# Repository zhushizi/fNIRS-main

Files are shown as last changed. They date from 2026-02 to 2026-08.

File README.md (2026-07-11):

# fNIRS 双接收源五波长上位机软件

本仓库现在只保留 **上位机软件部分**，并已切换到 **双接收源 + 五波长** 的 26B 串口协议。
软件接收 `S1_D1`（长距 3.0 cm）与 `S1_D2`（短距 1.0 cm）两个接收源、五个光源波长（850 / 810 / 770 / 730 / 700 nm）的光强数据，完成采集、配对、短距回归校正（SSR）、广义 MBLL 与 rSO₂ 估算，输出 **HbO / HbR / Cyt** 三色团浓度变化以及 **rSO₂**。

> 数据链路：安卓 App 独占 UART 启停，把设备串口字节经 **TCP/JSON** 转发给 PC 解码端（PC 作为 TCP Server 被动接收）。PC 端在采集中并行做在线分析并把结果回传安卓绘图，采集结束后再做一次离线终算落盘。

## 当前协议摘要

- **波特率**：`115200`
- **帧头**：`0x55 0xAA`
- **固定帧长**：`0x1A`（26 字节）
- **帧类型**：
  - `0x01`：指令帧（上位机 -> 下位机）
  - `0x02`：数据帧（下位机 -> 上位机）
  - `0x03`：应答帧（双向 ACK）
- **payload**：`21B`
- **校验**：从长度字节到 payload 末尾的累加和低字节
- **当前固件不回 ACK**：`protocol.send_frame_with_ack` 暂时跳过 ACK 判断（由安卓侧控制 UART）

## 当前几何与算法假设

- **物理通道**：双接收源
  - `S1_D1`：源探距离默认 `3.0 cm`（长距，配置在 `software/config.py`）
  - `S1_D2`：源探距离默认 `1.0 cm`（短距，用于短距回归校正）
- **波长编码**（数据帧 payload byte0 = `Wavelength`）：
  - `0x00`：未点亮（OFF，配对前丢弃）
  - `0x01`：850nm
  - `0x02`：810nm
  - `0x03`：770nm
  - `0x04`：730nm
  - `0x05`：700nm
- **接收源编码**（数据帧 payload byte1 = `DetectorId`）：
  - `0x01`：`S1_D1`
  - `0x02`：`S1_D2`
- **采样值**：payload `byte2:6`，4 字节大端无符号
- **采集通道编码**（数据帧 payload byte6 = `ChannelId`，与接收源/波长正交）：
  - `0x01`：通道1
  - `0x02`：通道2
  - `0x00`/缺省：归入通道1
  - 每个采集通道内部各有完整的双接收源×五波长，反演链路在每个通道内各跑一套；回传安卓时用 `channel` 字段区分
- **反演**：分步广义 MBLL 先解 HbO/HbR，再从残差投影估 Cyt（oxCCO，UCL-NIR 差分消光系数）
- **rSO₂**：基于 30–60s 基线段假设（基线 HbT≈80μM、rSO₂≈65%）把 ΔHbO/ΔHbR 转成血氧饱和度
- **输出通道**：由 `config.OUTPUT_CHANNEL` 选择，可选 `S1_D1` / `S1_D2` / `S1_D1_ssr`，默认 `S1_D1_ssr`（短距回归校正后的长距通道）

## 快速开始

1. 安装依赖

```bash
cd software
pip install -r requirements.txt
```

2. 配置参数

编辑 `software/config.py`：

- `SERIAL_PORT`（仅旧串口脚本使用）
- `BAUD_RATE`
- `HOST_TCP_DEFAULT_PORT`（安卓 TCP 连接端口，默认 `9000`）
- `DETECTOR_CHANNELS` / `WAVELENGTH_CHANNELS`（几何与波长表）
- `OUTPUT_CHANNEL`（输出通道）

3. 运行方式（当前主链路）

```bash
cd software
# 启动 TCP 解码端，等待安卓连接；采集 + 在线回传 + 离线终算
python fNIRS_processing.py

# 同时在 PC 端镜像绘制发往安卓的曲线
python fNIRS_processing.py --live_plot

# 打印 TCP 收发日志
python fNIRS_processing.py --tcp_debug
```

## 输出文件

每次采集在 `software/result_table/<时间戳>/` 下生成一组文件。**采集通道相关的文件按通道各写一份**（后缀 `_ch1` / `_ch2`），原始数据合写一份并带 `ChannelId` 列：

- `all_groups.csv`
  - 原始采集数据（所有通道合写一份）
  - 列：`Time (s), ChannelId, DetectorId, Channel, Wavelength, Value`
- `interleaved_output_ch{n}.csv`
  - 该通道 2 接收源 × 5 波长配对后的光强宽表
  - 列：`Time (s), S1_D1_850, S1_D1_810, ..., S1_D2_700`
- `processed_output_ch{n}.csv`
  - 该通道广义 MBLL + SSR 输出（列前缀取自 `OUTPUT_CHANNEL`）
  - 列风格：`Time, S1_D1_ssr_hbo, S1_D1_ssr_hbr, S1_D1_ssr_cyt`
- `android_live_output_ch{n}.csv`
  - 该通道在线分析过程中实际回传安卓的曲线副本

> 只出现一个通道时就只生成该通道那一套文件（例如仅通道1 时只有 `*_ch1.csv`）。

## 主要文件

- `software/config.py`：串口/TCP 参数、几何与五波长表、消光系数、输出通道
- `software/protocol.py`：26B 协议组帧 / 拆帧 / 校验
- `software/fNIRS_processing.py`：主入口（解析参数后调用 `run_pipeline`）
- `software/fnirs_pipeline/`：采集 → 预处理 → 配对 → MBLL/SSR 的离线/在线管线
- `software/online_android/`：安卓 TCP 桥接、在线分析后台线程、rSO₂、回传与绘图

更详细的数据链路说明见 `software/fNIRS_processing_pipeline.md` 与 `software/README.md`。

## 历史 / 单通道脚本

下列脚本来自旧的单通道双波长（660/940）版本，部分仍走本地串口，主链路已不再使用，仅作参考或离线回放：
`adc_live.py`、`adc_animation.py`、`mBLL_animation.py`、`visualizer.py`（+ `index.html`）、`hbo_hbr_live.py`、`data_analysis.py`、`nirs_viewer.py`、`rso2_from_processed.py`。

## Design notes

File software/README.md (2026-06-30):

# fNIRS Dual-Detector Five-Wavelength Software

This directory contains the host-side software for the **dual-detector, five-wavelength** fNIRS workflow.
It targets the **26-byte framed serial protocol** carried over an **Android TCP bridge**, and assumes two
receiver channels — `S1_D1` (long, 3.0 cm) and `S1_D2` (short, 1.0 cm) — each sampled under five emitter
wavelengths (`850 / 810 / 770 / 730 / 700 nm`).

The Android app owns the UART (start/stop), forwards raw serial bytes to the PC over TCP/JSON, and the PC
acts as a passive TCP **server** that decodes frames, runs analysis, and streams `HbO / HbR / Cyt / rSO₂`
results back to the phone for live plotting.

## Core Features

- **Framed serial protocol** (`protocol.py`)
  - `0x55 0xAA` frame header
  - fixed `26B` frame length
  - checksum validation
  - current firmware does not ACK; `send_frame_with_ack` skips the ACK wait

- **Android TCP bridge** (`online_android/tcp_bridge.py`)
  - PC listens on `HOST_TCP_DEFAULT_PORT` (default `9000`)
  - Android sends `serial_data` (base64-encoded raw frames); PC exposes a serial-like `read()`
  - PC sends back `live_analysis_batch` and `analysis_result`

- **Dual-detector acquisition**
  - one intensity value per data frame, tagged with detector id and wavelength code
  - raw capture stored in `all_groups.csv`

- **Processing**
  - per-(detector, wavelength) low-pass filtering
  - segment RMS by `(DetectorId, Wavelength)` runs
  - 2 detectors × 5 wavelengths pairing into an intensity wide table
  - intensities → OD changes → robust band-pass (with decimation)
  - **short-separation regression (SSR)**: short detector regressed out of the long detector
  - **stepwise generalized MBLL**: solve HbO/HbR first, then estimate Cyt from the residual projection
  - **rSO₂** estimation from ΔHbO/ΔHbR over a fixed baseline window

- **Online + offline**
  - online: background worker re-runs the full session each tick and streams full series to Android
  - offline: after capture finishes, a final pass writes `processed_output.csv`

## Protocol Summary

### Common Frame Layout

| Field | Size |
|---|---|
| Header | 2 bytes (`0x55 0xAA`) |
| Length | 1 byte (`0x1A`) |
| Type | 1 byte |
| Payload | 21 bytes |
| Checksum | 1 byte |

### Frame Types

- `0x01`: command frame
- `0x02`: data frame
- `0x03`: ACK frame

### Command Payload (`0x01`)

| Byte | Meaning |
|---|---|
| 0 | start/stop (`0x00` stop, `0x01` start) |
| 1 | intensity (`0x00`~`0xFF`) |
| 2 | channel/command code |
| 3-20 | reserved, currently `0x00` |

### Data Payload (`0x02`)

| Byte | Meaning |
|---|---|
| 0 | wavelength code (`0x00=off`, `0x01=850`, `0x02=810`, `0x03=770`, `0x04=730`, `0x05=700` nm) |
| 1 | detector id (`0x01=S1_D1`, `0x02=S1_D2`) |
| 2-5 | sampled value, 4-byte big-endian unsigned |
| 6-20 | reserved |

`Wavelength=0x00` (off) rows are dropped before wavelength pairing.

## Configuration

Edit `config.py` before running:

- `SERIAL_PORT`, `BAUD_RATE` (legacy single-channel serial scripts only)
- `HOST_TCP_LISTEN_HOST`, `HOST_TCP_DEFAULT_PORT` (Android TCP bridge)
- `DETECTOR_CHANNELS` (names, codes, source-detector distances)
- `WAVELENGTH_CHANNELS` (codes + emitter/MBLL wavelengths)
- `OUTPUT_CHANNEL` (`S1_D1` | `S1_D2` | `S1_D1_ssr`, default `S1_D1_ssr`)
- `BP_LOW_HZ` / `BP_HIGH_HZ` / `BP_ORDER` (OD band-pass)

`config.py` validates these tables on import (`_validate_wavelength_channels`, `_validate_output_channel`).

## Main Entry Point

### `fNIRS_processing.py`

Thin CLI wrapper. Parses TCP options and calls `fnirs_pipeline.run_pipeline`, which:

1. opens the Android TCP bridge and waits for a client,
2. captures raw frames into `all_groups.csv` while a background worker streams live analysis,
3. builds `interleaved_output.csv` (paired intensities),
4. runs SSR + generalized MBLL and writes `processed_output.csv`,
5. sends a final `analysis_result` to Android.

```bash
python fNIRS_processing.py                 # capture + online + offline
python fNIRS_processing.py --live_plot     # also mirror the Android stream on a PC plot
python fNIRS_processing.py --tcp_debug     # print TCP rx/tx logs
```

## CSV Outputs

Written under `result_table/<timestamp>/`.

### `all_groups.csv`

```text
Time (s),DetectorId,Channel,Wavelength,Value
```

### `interleaved_output.csv`

```text
Time (s),S1_D1_850,S1_D1_810,S1_D1_770,S1_D1_730,S1_D1_700,S1_D2_850,...,S1_D2_700
```

### `processed_output.csv`

Column prefix follows `OUTPUT_CHANNEL` (default `S1_D1_ssr`):

```text
Time,S1_D1_ssr_hbo,S1_D1_ssr_hbr,S1_D1_ssr_cyt
```

### `android_live_output.csv`

A copy of the series actually streamed to Android during online analysis.

## Module Layout

- `fnirs_pipeline/` — offline/online pipeline
  - `pipeline.py`: `run_pipeline` orchestration
  - `capture.py`: TCP capture + online session wiring
  - `preprocessing.py`: low-pass, RMS segmentation, wavelength-cycle aggregation
  - `mbll.py`: OD, band-pass, SSR, generalized MBLL, rSO₂ summary
- `online_android/` — Android-facing live analysis
  - `tcp_bridge.py`: Host TCP protocol (server side)
  - `worker.py` / `session.py` / `buffer.py`: background analysis lifecycle
  - `batch_builder.py` / `reporter.py` / `batch_recorder.py`: build, send, record live batches
  - `rso2.py`: rSO₂ from ΔHbO/ΔHbR
  - `live_plotter.py`: optional PC-side mirror plot

## Legacy / Single-Channel Scripts

These come from the earlier single-channel 660/940 design and are kept for reference or offline replay;
some still talk directly to a local serial port and are **not** part of the current TCP main path:
`adc_live.py`, `adc_animation.py`, `mBLL_animation.py`, `visualizer.py` (+ `index.html`),
`hbo_hbr_live.py`, `data_analysis.py`, `nirs_viewer.py`, `rso2_from_processed.py`.

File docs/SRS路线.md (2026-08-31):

# 绝对脑血氧（SRS）技术路线

> 目标：在现有 MBLL 相对量路线之外，增加**空间分辨光谱（SRS）**通路，输出绝对组织氧饱和度 TOI/rSO₂。
>
> ⚠️ **本路线与现有送检主线相互独立。** `检验方法.md` 的附录 BB 体模试验、`软件验证报告.md` 的离线链路验证均不受影响；SRS 失败也不影响已有成果。

---

## 0. 结论摘要

| 项 | 结论 |
|---|---|
| **技术可行性** | ✅ 链路闭合，CW + 多距离 + SRS 可产出绝对血氧读数 |
| **硬件配置** | ✅ 拟定的 1 短 + 3 长、五波长 **优于商用基线**（NIRO/EGOS 均为 2 长距 + 3 波长） |
| **算法** | ✅ 原理公开，参考实现见 [`tools/srs_reference.py`](tools/srs_reference.py)，自检通过 |
| **最大门槛** | ⚠️ **波长间增益一致性 <1%** —— 标定工艺问题，非算法问题 |
| **第二门槛** | ⚠️ **μs′ 光谱形状**（§3.2）—— 固定假设时谱指数偏 ±0.4 → TOI 偏 ±3.7 %O₂；五波长可自解谱指数把该项降到 0.03 %O₂，代价是对幂律失配更敏感。**属生物变异，体模标定解决不了** |
| **体模** | ✅ 已询厂并逐条判定（§4.5）。逐波长认证**非必需**——3×4 二维矩阵可自标增益；但自标定会**静默失败**，须留独立参照 |
| **法规** | ❌ **无对应国标条款**（GB/T 44423 的"空间分辨率"指通道间距，非 SRS） |

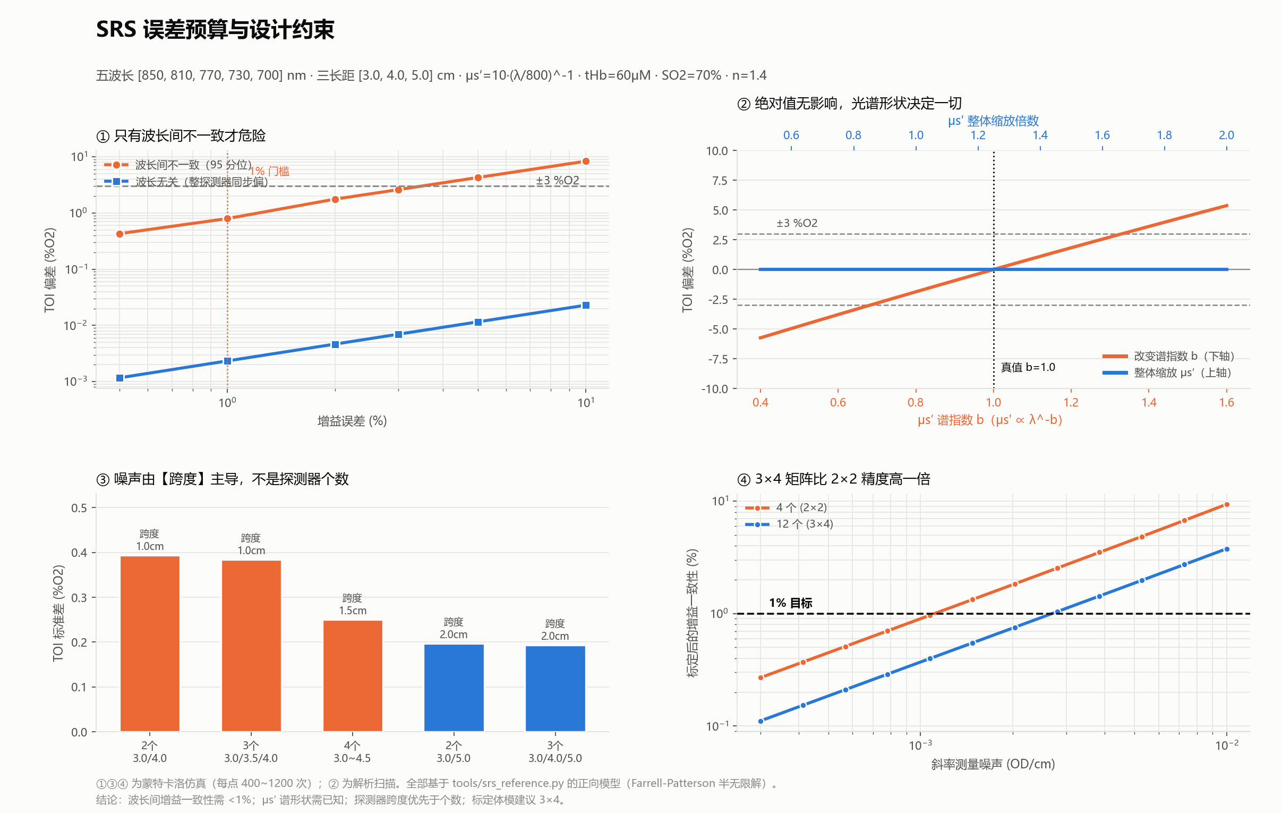
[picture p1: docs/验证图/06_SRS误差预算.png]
SRS 误差预算


---

## 1. 算法

### 1.1 公开与私有的分界

| 部分 | 状态 |
|---|---|
| 扩散方程半无限解（Farrell-Patterson） | ✅ 公开 |
| SRS 工作方程 | ✅ 公开 |
| μa 反演、ε → TOI | ✅ 公开 |
| **μs′(λ) 具体模型** | ❌ 厂商私有 —— **但本项目可绕过，见下** |
| **标定常数、温补、伪影抑制、信号质量判据** | ❌ 私有 |

> EGOS-600 验证论文原文：「...and **by assuming** the wavelength dependence of the reduced scattering coefficient, the ratio of the absorption coefficient under at least two wavelengths can be calculated.」
>
> 关键词是 **assuming** —— 连滨松也是假设，各家假设什么不公开。该论文亦承认两台 SRS 设备互比偏倚 8%，原因「**remains unknown**」。

**⇒ 两家商用设备的私有假设互相就不一致，且无人知道谁对——没有金标准可对齐。**
目标因此不是「拿到他们的模型」，而是「有一个自己能标定、能验证、能向审评说清楚的模型」。

#### 私有项的三类拆分与对策

| 类别 | 内容 | 对策 |
|---|---|---|
| **A 标定常数** | 增益归一化、系统偏差修正 | **本来就须自标**——常数与本机探头几何/LED/PD 绑定，他人的无法移植。§3.2.2 的 b 恒偏 **+0.10** 即此类典型，由 §4.6 体模矩阵产出 |
| **B μs′(λ) 模型** | 假设何种谱形 | ✅ **本项目绕过**——五波长超定可自解谱指数（§2.3、§3.2.2）。NIRO/EGOS 均为 3 波长（4 未知 / 3 方程，欠定），**其「必须假设」是硬件限制所迫，非藏有诀窍** |
| **C 工程 know-how** | 温补、伪影抑制、质量判据 | 无捷径但无门槛：温补为板载温度传感 + 标定扫温建表；伪影抑制与质量判据学术界方法公开，本项目贴肤检测已有同类基础 |

**注册角度**：私有模型对本项目是负担而非资产——审评要求算法可解释、可追溯。本路线正向模型全公开、谱指数自解（只需披露约束区间而非一个不可溯源的假设）、标定常数来自可溯源体模、参考实现附自检。

⚠️ **专利风险**：公式属公开文献，但**具体实现组合、探头结构、标定流程可能受专利保护**（如苏州爱琴，见 §5）。需在硬件定型前做专业 FTO 检索——**本文档不构成专利意见**。

### 1.2 完整公式

**① 半无限介质稳态漫反射**

$$R(\rho)=\frac{1}{4\pi}\left[z_0\left(\mu_{eff}+\frac{1}{r_1}\right)\frac{e^{-\mu_{eff}r_1}}{r_1^2}+(z_0+2z_b)\left(\mu_{eff}+\frac{1}{r_2}\right)\frac{e^{-\mu_{eff}r_2}}{r_2^2}\right]$$

$$z_0=\frac{1}{\mu_a+\mu_s'},\quad D=\frac{1}{3(\mu_a+\mu_s')},\quad z_b=2D\frac{1+R_{eff}}{1-R_{eff}}$$

$$r_1=\sqrt{\rho^2+z_0^2},\qquad r_2=\sqrt{\rho^2+(z_0+2z_b)^2}$$

`R_eff` 由折射率决定 —— **这是折射率进入结果的入口**，见 §4.2。

**② SRS 工作方程（大 ρ 渐近）**

$$\boxed{\frac{\partial A}{\partial\rho}=\frac{1}{\ln 10}\left(\mu_{eff}+\frac{2}{\rho}\right)}$$

**③ 反演**

$$\mu_{eff}=\ln 10\cdot\frac{\partial A}{\partial\rho}-\frac{2}{\bar\rho},\qquad \mu_a=\frac{\mu_{eff}^2}{3\mu_s'}$$

（严格式为 $\mu_{eff}=\sqrt{3\mu_a(\mu_a+\mu_s')}$，因 $\mu_a\ll\mu_s'$ 简化）

**④ 解色团**

$$\mu_a(\lambda)=\ln 10\left[\varepsilon_{HbO}(\lambda)c_{HbO}+\varepsilon_{HbR}(\lambda)c_{HbR}\right],\qquad \text{TOI}=\frac{c_{HbO}}{c_{HbO}+c_{HbR}}\times 100\%$$

### 1.3 一个必须理解的性质

⚠️ **SRS 给出绝对饱和度，但给不出绝对浓度。**

μs′ 整体缩放 k 倍 → μa 缩放 1/k → c_HbO 与 c_HbR 同步缩放 → **比值不变**。

实测（图 ②，蓝线）：μs′ ×0.7 / ×1.0 / ×1.5，TOI 偏差均为 **−0.00**。

这就是为什么 NIRO 报告 TOI（绝对）的同时只能报 nTHI（归一化，相对）。

### 1.4 参考实现自检

[`tools/srs_reference.py --selftest`](tools/srs_reference.py) 实测：

| 真值 SO₂ | 反演 TOI | 偏差 |
|---|---|---|
| 30% | 30.34% | +0.34 |
| 50% | 50.13% | +0.13 |
| 70% | 69.83% | −0.17 |
| 90% | 89.45% | −0.55 |

单调、线性、偏差 <0.6 %O₂。

⚠️ 但 μa 反演值系统性偏高约 **2.8%**（0.1424 vs 真值 0.1385）—— **渐近斜率法相对精确解的固有偏差**，在比值中大部分抵消，剩余需由体模标定吸收。

---

## 2. 硬件配置

### 2.1 探头布局

```
      [S1]  五波长 LED  850/810/770/730/700 nm
   ●     ●      ●      ●
  D_s   D1     D2     D3
  1.0   3.0    4.0    5.0 cm
   │     └──────┴──────┘
   │        SRS 三点
   └─ SSR（MBLL 通路，可选，失效自动退化）
```

**短距保留的理由**：供现有 MBLL/SSR 通路使用，并可作贴合质量监测。**对 SRS 无用**（ρ<2 cm 扩散近似不成立），但保留成本几乎为零。

这也是 NIRO-200NX 的双通路做法：SRS 出绝对 rSO₂，MBLL 出 Δ 量。

### 2.2 探测器数量与距离：跨度优先于个数

**斜率对各探测器的权重** $w_i=(\rho_i-\bar\rho)/\sum(\rho_j-\bar\rho)^2$：

| 距离配置 | 权重 w |
|---|---|
| 3.0 / 4.0 / 5.0 | **[−0.5, 0, +0.5]** |
| 3.0 / 3.5 / 4.0 | [−1, 0, +1] |
| 3.0 / 4.0 / 4.5 | [−0.714, +0.143, +0.571] |

⚠️ **等间距三点时中间探测器权重为 0** —— 其增益误差不影响斜率，但仍参与线性度自检。

**噪声实测**（逐探测器逐波长独立噪声 0.002 OD，图 ③）：

| 布局 | 跨度 | TOI 标准差 |
|---|---|---|
| 2 个 3.0/4.0 | 1.0 cm | 0.394 |
| 3 个 3.0/3.5/4.0 | 1.0 cm | 0.384 |
| 4 个 3.0~4.5 | 1.5 cm | 0.250 |
| 2 个 3.0/5.0 | 2.0 cm | **0.197** |
| **3 个 3.0/4.0/5.0** | **2.0 cm** | **0.193** |

**跨度 2.0 cm 的 2 个探测器优于跨度 1.5 cm 的 4 个。** 增加个数而不增加跨度几乎无收益。

**选 3 个而非 2 个的理由不是精度，是故障检测**：

| 单探测器耦合偏差 | 3 点拟合残差 RMS |
|---|---|
| 5% | 0.00577 OD |
| 10% | 0.01529 OD |
| 20% | 0.03311 OD |

⚠️ **2 个探测器时两点必共线，残差恒为 0，此类故障完全不可见。** 商用产品（NIRO/EGOS）用 2 个，靠的是绝对光强水平、饱和检测等其他质量指标补这个洞。

### 2.3 波长数：五波长优于商用基线

同样 3 探测器、斜率噪声 0.002 OD/cm：

| 配置 | 无噪偏差 | TOI 标准差 |
|---|---|---|
| **本项目 5 波长** | −0.17 | **0.277** |
| NIRO-200NX 3 波长 (735/810/850) | −0.39 | 0.486 |
| EGOS-600 3 波长 (760/810/850) | −0.03 | 0.428 |
| 最少 2 波长 | −0.09 | 0.455 |

**噪声低约 40%**，且三波长丢一个即无解，五波长可降级运行。

**更强的一条论据：只有 ≥4 波长才能自解 μs′ 谱指数**（§3.2）。自解需 4 个未知数（c_HbO、c_HbR、a、b）：

| 配置 | 未知数/方程 | 真实 b=0.6 / 1.0 / 1.4 下的 SO₂ | 波动 |
|---|---|---|---|
| NIRO 3 波长 | 4/3　**欠定** | 70.45 / 70.05 / 70.56 | 0.51 |
| EGOS 3 波长 | 4/3　**欠定** | 70.80 / 70.13 / 70.79 | 0.67 |
| 4 波长 | 4/4　恰定 | 70.47 / 70.48 / 70.47 | **0.01** |
| **本项目 5 波长** | 4/5　**超定** | 70.70 / 70.71 / 70.73 | **0.03** |

三波长虽形式上欠定，在生理边界约束下解仍收敛（b 不随起点漂移），但**对真实 b 变化的稳健性差一个数量级**。五波长在恰定之上还留有 1 个自由度用于抑制噪声。

### 2.4 ⚠️ 动态范围 50.6 dB

以 3.0 cm 为 0 dB（μs′=10, μa≈0.13 cm⁻¹）：

| 距离 | 相对 3.0 cm |
|---|---|
| **1.0 cm** | **+24.8 ~ +27.2 dB** |
| 3.0 cm | 0 dB |
| 4.0 cm | −10.1 ~ −11.4 dB |
| **5.0 cm** | **−19.7 ~ −22.1 dB** |

全组合（4 距离 × 5 波长）跨度 **50.6 dB = 11 万倍**。

**但逐探测器内部的波长间跨度很小**：

| 距离 | 波长间跨度 |
|---|---|
| 1.0 cm | 1.2 dB |
| 3.0 cm | 3.6 dB |
| 5.0 cm | 6.1 dB |

**⇒ 增益分配策略：每探测器一个独立增益档，档内五波长共用。** 只需 4 个增益档，不是 20 个。

而 SRS 要求的「波长间一致性 <1%」正好落在**档内**（同一 PD、同一跨阻），天然好做；**探测器之间的差异靠体模标定解决**。

⚠️ 这条使 `检验方法.md` 的判据 **R2（各探测器支持独立增益档位）从"建议"变为"必需"**。

### 2.5 探头尺寸

- 光源到 5.0 cm 探测器 + 封装边缘 → **总长约 6.0~6.5 cm**
- 成人前额（两颞线间）约 10~12 cm，可容纳但要求贴合面平整
- ⚠️ **儿童/新生儿放不下** —— EGOS-600 儿童档改用 20/30 mm 即此原因；覆盖儿科需第二种探头规格

### 2.6 采样率不受影响

多探测器**并行采样、共享时间戳**，增加探测器不延长时分周期。现有 1 Hz 配对率不变。

---

## 3. 误差预算

### 3.1 增益误差：只有波长间不一致才危险

（图 ①，蒙特卡洛 400 次/点）

| 误差 | 波长间不一致（95 分位） | 波长无关（整探测器同步偏） |
|---|---|---|
| 0.5% | 0.42 %O₂ | 0.001 |
| **1%** | **0.80** | 0.002 |
| **2%** | **1.77** | 0.005 |
| 3% | 2.9 | 0.007 |
| 5% | 4.28 ⚠️ | 0.011 |
| 10% | 8.5 ⚠️ | **0.023** |

**波长无关的增益误差在比值中约掉，10% 只带来 0.023 %O₂。**

**⇒ 门槛：波长间增益一致性 <1%**（对应 TOI 偏差 <1 %O₂，留 3 倍余量）。

### 3.2 μs′：绝对值无影响，谱形状可自解但有代价

（图 ②）

| 扰动 | TOI 偏差 |
|---|---|
| μs′ 整体 ×0.7 / ×1.5 | **−0.00 / −0.00** |
| μs′ ∝ λ^−0.6（真值 −1.0） | **−3.78** ⚠️ |
| μs′ ∝ λ^−1.4 | **+3.62** ⚠️ |

**固定假设一个谱指数 b 时，b 偏 ±0.4 → TOI 偏 ±3.7 %O₂。**

#### 3.2.1 根源：CW 的原理性简并

斜率法只给出一个 μeff，而 $\mu_{eff}=\sqrt{3\mu_a(\mu_a+\mu_s')}$ 把两者**乘在一起**：

| μs′ | 需配的 μa | 得到的 μeff |
|---|---|---|
| ×0.7 | ×1.43 | 2.0131 |
| ×1.0 | ×1.00 | 2.0005 |
| ×1.4 | ×0.71 | 1.9946 |

**一条简并线。** 单波长下 μa 与 μs′ 无法分离——这是 CW（连续波）光源的固有局限，频域（FD）/时域（TD）设备可独立测出 μs′，CW 不能。

#### 3.2.2 但五波长可以打破简并

加上「μs′(λ) = a·(λ/800)^−b」这一约束后，未知数为 4（c_HbO、c_HbR、a、b），而五波长给出 5 个 μeff，**超定**。

实测（`toi_fit_scattering()`，自检第 5 项）：

| 真实 μs′ 谱形 | 自解 b | 自解 SO₂ | 固定假设 b=1.0 |
|---|---|---|---|
| 纯幂律 b=0.6 | 0.70 | **70.70** ✅ | 73.45 ❌ |
| 纯幂律 b=1.0 | 1.10 | **70.71** ✅ | 69.83 ✅ |
| 纯幂律 b=1.4 | 1.50 | **70.73** ✅ | 66.05 ❌ |
| 两层混合（b=0.6 与 1.3 各半） | 1.05 | **70.68** ✅ | 70.25 ✅ |
| 幂律叠加 4% 正弦畸变 | 1.42 | 73.79 ❌ | **69.79** ✅ |

*（真值 70.00；b 从 0.6/1.0/1.8 三个不同起点出发均收敛到同一解）*

- 真实 b 在 0.6~1.4 变化时，**自解 SO₂ 波动仅 0.03 %O₂**，固定假设为 **7.40 %O₂**
- 自解 b 恒偏 **+0.10**（渐近近似导致的系统偏差，可由体模标定扣除）

⇒ **「μs′ 谱形状必须已知」这一说法过强。** 五波长配置本身即可解出谱指数。

**代价**：多一个自由参数既吸收真实变化，也吸收模型误差——上表末行，μs′ 偏离幂律时自解反而更差（+3.79 vs −0.21）。缓解手段是 `toi_fit_scattering(..., b_bounds=(0.5,1.6), b_weight=λ)`，将 b 限制在生理区间并加正则项；**不加约束时 b 会在畸变下顶到边界**（实测某些谱形下跑到 3.0）。

#### 3.2.3 剩余的不确定性是生物学的，不是仪器的

幂律成不成立，取决于：

| 来源 | 机理 |
|---|---|
| **分层结构** | 头皮/颅骨/脑各层谱指数不同，3~5 cm 采到的是加权混合 |
| **权重不固定** | 颅骨厚度、脑脊液层、贴合位置改变混合权重 |
| **水与脂质吸收** | 850 nm 一侧抬头，会被误读为散射谱畸变 |
| **个体与年龄** | 组织成分差异（髓鞘化程度等） |

⚠️ **与 §3.1 增益问题的关键区别：体模标定解决不了这一条。** 体模的 μs′ 谱是自己配的，病人的不是——标定校准的是**仪器**，不是**人**。

⚠️ **适用边界**：以上全部在**均匀半无限介质**下得到。「两层混合」仅混合了 μs′ 谱，非真实分层几何。分层头部下自解 b 的表现**未经验证**，需蒙特卡洛或分层扩散模型确认。

⇒ **建议**：采用自解谱指数并加生理区间约束；**说明书需披露所用 μs′(λ) 模型与 b 的约束范围**（与披露 DPF 公式同理）。体模端的要求见 §4.2 —— 逐波长认证并非必需，但需有独立参照以校验结构假设。

### 3.3 浅层抑制：3~11 倍，不是无穷大

两层模型，浅层光程参数化为 $L_1(\rho)=L_{1,0}\rho^\gamma$：

| γ | SRS 浅层灵敏度 | 单距 | 抑制倍数 |
|---|---|---|---|
| 0.0（理想） | 0.0000 | 0.1667 | ∞ |
| 0.1 | 0.0146 | 0.1667 | **11.4×** |
| 0.2 | 0.0296 | 0.1667 | **5.6×** |
| 0.3 | 0.0450 | 0.1667 | **3.7×** |
| 1.0 | 0.1667 | 0.1667 | 1.0× |

**机制**：光进出头皮各一次，浅层光程对 ρ 依赖弱，求导后被大幅压制。但 γ>0 使抑制不彻底。

⚠️ **γ 的真实取值需用自己的探头几何与组织参数确定**，上表为参数化演示。

⚠️ **均质体模验不出这个特性** —— 需分层体模。EGOS-600 论文亦承认此局限：「the sensor geometry in relation to the multi-layered structure of the human tissue-skin, scalp, and skull are not emulated」。

---

## 4. 体模与标定

### 4.1 ⚠️ 体模属性对两条路线的意义完全相反

| 参数 | SRS | MBLL / 附录 BB |
|---|---|---|
| **每波长 μa/μs′** | ⭐ 标定基准 | ❌ 完全不需要 |
| **折射率 n** | ⭐ 影响斜率 | ❌ 两状态间约掉 |
| 尺寸 | ⭐ 半无限解成立 | ⚠️ 需要，理由不同 |
| 温度/老化 | ⭐ 标定值会漂 | ❌ 相对测量不受影响 |

**根本原因**：MBLL 测 $\Delta A=\log_{10}(I_A/I_B)$，体模属性在两次测量中完全约掉，溯源靠孔径面积比（纯几何）。SRS 测绝对斜率，无比值可约。

⚠️ **推论：附录 BB 的变孔径体模对 SRS 完全无效** —— 孔径变化使所有探测器同步变暗，**斜率不变**。

### 4.2 增益标定：可自标，但会静默失败

增益与 μs′ 的**签名不同**，因而可分离：增益偏移是斜率上的**加性**常数（与体模光学性质无关），μs′ 误差是 μa 上的**乘性**偏差（随体模变化）。

⚠️ **斜率只受一个线性组合影响** ⇒ 每波长只需标定**一个**有效增益参数，五波长共 5 个，不是 15 个。

**实测：不知道 μa/μs′ 绝对值也能自标增益**（假设 μs′ 逐块幂律、μa 为同一吸收剂的不同浓度）：

| 体模矩阵 | 波长选择性残差 | 判定 |
|---|---|---|
| 3×4，噪声 5e-4 | 0.00146 | ✅ |
| 3×4，μs′ 幂律失配 3% | 0.00028 | ✅ 稳健 |
| **1×4（只变 μa）** | 0.03855 | ❌ |
| **3×1（只变 μs′）** | 0.14567 | ❌ |

⇒ **必须 μa 与 μs′ 二维都变化。** 残差 0.003 → TOI 0.56 %O₂；0.005 → 0.89 %O₂。

⚠️⚠️ **但自标定对「同一吸收剂谱形共享」假设极其敏感，且无法自诊断：**

| 情形 | 拟合残差 | 实际误差 |
|---|---|---|
| 噪声 1e-3、无漂移 | 8.90e−4 | 0.00284 ✅ |
| 噪声 5e-4、**谱形漂移 2%** | 9.63e−4 | **0.03809** ❌ |

**残差几乎相同，实际误差差 13 倍。** 而谱形漂移有真实机制：**TiO₂ 本身有吸收，各块散射档位不同 → 对 μa 的贡献随之变化** —— 这正是 3×4 矩阵必然发生的事。

⇒ **认证值的价值不是提高精度，而是提供独立交叉校验**（各块反推的 G 应一致，离散即报警）。**哪怕只有单一波长的准确认证值也有用。**

### 4.3 3×4 矩阵的必要性

（图 ④）

| 斜率噪声 | 4 个 (2×2) | **12 个 (3×4)** |
|---|---|---|
| 0.001 OD/cm | 0.36% | **0.16%** |
| **0.002** | 0.73% | **0.32%** ✅ |
| 0.005 | 1.82% ❌ | 0.80% ✅ |

**3×4 不是冗余，是刚好够。**

**国际依据**：MEDPHOT 协议（Pifferi 等，*Appl. Opt.* 2005, 44(11):2104）的标准体模集即为**二维网格**——μa 8 档（0~0.35 cm⁻¹）× μs′ 4 档（5~20 cm⁻¹）= 32 块，环氧树脂 + TiO₂ + 黑色碳粉，**标称仅在 800 nm 单一波长**。可直接引用其区间与结构与厂商议价。

### 4.4 尺寸与折射率

| 项 | 要求 | 厂商 Φ100×50mm | 判定 |
|---|---|---|---|
| 边缘余量 | > 3/μeff（最大 2.15 cm） | 2.5 cm | ✅ |
| 厚度 | > 3/μeff | 5.0 cm | ✅ |
| 折射率 | 越接近组织 1.40 越好 | **1.42** | ✅ 斜率仅偏 **0.069%** |

⚠️ **3×4 若为小块拼接，须确认每块单独满足**，否则探头压在某块上时旁边是不同材料，形成侧向边界。

### 4.5 体模厂家答复与待办

| # | 问题 | 答复 | 判定 |
|---|---|---|---|
| 1 | 五波长分别给值 | 仅 685/808/830/980 | ⚠️ **730/770 落在 123nm 空档内** |
| 2 | 折射率 | 1.42 | ✅ |
| 3 | 尺寸 | Φ100 × 50 mm | ✅ |
| 4 | 不确定度与方法 | 积分球 + 逆倍加法(IAD) | ⚠️ 方法可信，**数值未给** |
| 5 | 覆盖范围 | "能" | ⚠️ 其论文实例 μs′ 仅 6.3~7.6，低于目标 8~12，需书面确认 |
| 6 | 均一性 | 镜检 + 多点测量 | ⚠️ **无数值指标** |
| 7 | 温度系数 / 保质期 | 5 年，实验室追踪 8 年无变化，唯一追踪码，留样 | ⚠️ 保质期优秀，**温度系数未答** |
| 8 | 分层体模 | 有，每层厚度与光学参数可定制，**每层独立标定** | ✅✅ 超出预期 |
| 9 | 血液体模 | 留腔自灌 / 或固体模拟 | ⚠️ 见 §4.6 |

**波长容差**（体模 μa 标称误差 → TOI 偏差）：

| 全波长同偏 5% | 仅 730/770 偏 5% | 仅 730/770 偏 10% |
|---|---|---|
| **+0.21** ✅ 共模被约掉 | **−0.67** | **−1.34** ⚠️ |

⇒ **门槛是「波长选择性误差 <5%」，不是绝对精度。** 而 IAD 的典型不确定度为 **μa 4~5%、μs′ 11~12%**，恰压在容差线上。μs′ 那 11~12% 无妨（绝对值在比值中约掉，谱形自解）。

**待追问三条**：① μa/μs′ 各自的不确定度数值（是否 GUM 溯源）；② 块内均一性的百分数指标；③ 温度系数（%/°C）。

**波长问题的解法**：厂商称「提供激光器即可标定」。反直觉的好处是——**用本机 LED 标定比窄线宽激光更贴合实际**，体模认证值就在设备真实看到的光谱条件下测得。需确认其 IAD 系统能否接受 ~30nm 半宽光源；不行则采购 700/730/770/850 四支激光二极管（通用件）。

### 4.6 ⚠️ 血液体模必须是液体，不能是固体腔

厂商论文中的腔体为 Φ6mm × 27~35mm —— 那是 **DOT 的思路**：在均匀背景中放小异物再成像找出。

**SRS 不成像，测的是体块平均光学参数。** ρ=3~5 cm 的敏感区体积约十余 cm³，Φ6mm 腔仅 0.85 cm³（占比约 5%），**腔内血液降氧几乎不改变体块 μa**，标定曲线拉不开。

⇒ 需**液体体模系统**：Intralipid（散射）+ 全血（吸收）+ 容器 + 脱氧装置，探头贴壁测量。

**为何必需**（见 §3.2、§7）：ε 表误差只能由降氧曲线多点标定吸收（残差 0.05 %O₂），**单点标定无效**——误差随 SO₂ 从 +2.23 变到 +7.76 %O₂。固体模拟血改不了饱和度，做不了降氧曲线。

**需提供给厂商的血液光学参数**（wray 表，μa = ln10·(ε_HbO·SO₂ + ε_HbR·(1−SO₂))·tHb）：

| λ(nm) | 700 | 730 | 770 | 810 | 850 |
|---|---|---|---|---|---|
| ε_HbO | 419.3 | 510.0 | 701.0 | 914.3 | 1097.0 |
| ε_HbR | 1827.7 | 1296.5 | 1425.0 | 798.7 | 781.0 |

需覆盖 μa **0.052 ~ 0.291 cm⁻¹**（SO₂ 30~90%、tHb 40~90 μM）。

⏰ **时序提醒**：血液体模的验证在增益标定**之后**，但**腔体/容器几何与分层层厚是制造期决定的**，且分两次下单会引入批次差异与二次交期。**存在性与几何须现在定，参数与降氧方案可后定。**
---

## 5. 竞品实况

| 厂家 | 产品 | 路线 | 探头几何 | 光源 |
|---|---|---|---|---|
| **滨松** | NIRO-200NX | **SRS** | 2 探测器 **40/50 mm** | 激光二极管 735/810/850 nm |
| **苏州爱琴** | EGOS-600A/B/C | **SRS** | 2 探测器 **30/40 mm**（成人）/ **20/30 mm**（儿童） | **LED** 760/810/850 nm |
| 中科搏锐 | BRS-1 / BRS-100 | **朗伯比尔**（招标文档载明） | 未公开 | 五波长 |
| 丹阳慧创 | NirScan | fNIRS 相对量 | 32 源 + 30 探测器，全 3 cm | — |
| 博联众科 | MOC 系列 | MBLL | — | — |

⚠️ **爱琴与中科搏锐路线不同**，不可混为一谈。

**苏州爱琴与丹阳慧创均为 `GB/T 44423—2024` 起草单位。**

### 5.1 EGOS-600 的验证方法（可直接借鉴）

**体外**：液态血液体模

> 40 mL 人全血 + 25 mL 20% 脂肪乳 + 935 mL 磷酸缓冲液（pH 7.35–7.45）
> 通纯氧 300 mL/min 约 5 min → SO₂ 到 100%
> 逐次加**连二亚硫酸钠（Na₂S₂O₄）**每次 10 mg 逐级降氧
> 覆盖 SO₂ **20–100%**，取 11 对测量

**体内**：31 名儿童（0.7–61 月龄）+ 20 名成人（18–73 岁），心脏术后一周内，两台设备探头**先后**贴前额中部，每 2–3 小时一次，各 100 对，Bland-Altman 分析。

### 5.2 ⚠️ 设备间一致性的现实预期

**两台都用 SRS、都经过标定**，人体上互比：

> 临床范围 SO₂ 40–80%：**偏倚 −8%，一致性界限 +4% ~ −20%**（该范围内仅 5 对测量）

论文原文：「This might be due to some small difference in algorithm between the two oximeters that **remains unknown**.」

**⇒ 送检时不可按"与某进口设备一致"立判据，那是立不住的。**

---

## 6. 分阶段路线

| 阶段 | 内容 | 判据 | 风险 |
|---|---|---|---|
| **1** | 硬件加 2 个 PD（4.0/5.0 cm）+ 每探测器独立增益 | 50.6 dB 全覆盖不饱和；`R1/R2` 通过 | 低 |
| **2** | 单块体模验斜率线性度 | 3 点拟合残差稳定、可重复 | 低 |
| **3** | **3×4 矩阵标定** | **有效增益一致性 <1%** | ⭐ **成败分水岭** |
| **4** | 未参与标定的体模块交叉验证 | μa 反演误差 | 中 |
| **5** | **液体**血液体模降氧（SO₂ 20~100%，§4.6） | 两参数修正后残差；TOI vs 血气 | 中，需血液制品 |
| **6** | 决定是否投人体标定 | — | 高，成本另一量级 |

**第 3 步是分水岭。** 做到 <1% 则继续；做不到说明工艺不足（温补、器件筛选、光路一致性），此时往下走只是浪费血液体模的钱。

⚠️ 全程**不动现有 MBLL 路线与附录 BB 送检主线**。

---

## 7. 与现有工作的关系

| | MBLL 路线（现有） | SRS 路线（新增） |
|---|---|---|
| 输出 | ΔHbO / ΔHbR / ΔCyt（相对） | **TOI / rSO₂（绝对）** |
| 送检依据 | **GB 9706.271 附录 BB**（规范性，<5% 判据） | **无对应条款** |
| 体模 | 变孔径，光学属性不需要 | μa×μs′ 二维固态矩阵（认证值非必需，需独立参照）+ **液体降氧体模** |
| 溯源 | 孔径面积比 + 校准功率计 | 体模矩阵结构 + 血液降氧曲线 |
| 增益要求 | 宽松（比值约掉） | **波长间 <1%** |
| 软件验证状态 | ✅ 已完成（见 `软件验证报告.md`） | 参考实现已自检，未上真实硬件 |
| 短距 | SSR 必需 | 不使用 |

**两条路线共用 ε 表** —— 但 SRS 更敏感：MBLL 有"两侧用同一张表就抵消"的退路，SRS 出绝对值，没有。

⚠️ 前已查明 `wray.csv` 与 Prahl 表在 HbO 短波端差 **30~45%**（700/730 nm）。实测该量级误差使 TOI 偏 **+5.7~8.4 %O₂**，且**强烈随 SO₂ 变化**（30% 时 +2.23，90% 时 +7.76）——**单点标定无效**。

⇒ 解法不是「选对表」，而是**血液体模降氧曲线的两参数线性修正**（实测残差 0.05 %O₂；换 tHb 后 0.47~0.65）。这使 §4.6 的液体体模从可选变为**必需**。

---

## 附 A：工具

| 脚本 | 用途 |
|---|---|
| [`tools/srs_reference.py`](tools/srs_reference.py) | SRS 参考实现（正向模型 + 反演 + 自检） |

```bash
python tools/srs_reference.py        # 自检
```

⚠️ 该实现**未经临床验证，不可用于诊断**，仅供算法验证与体模标定实验。

## 附 B：出处

| 内容 | 出处 |
|---|---|
| EGOS-600 与 NIRO-200NX 对照验证、两者几何与波长、血液体模方法、8% 偏倚 | Han D, et al. *J Clin Exp Cardiolog* **7**:440 (2016), DOI [10.4172/2155-9880.1000440](https://doi.org/10.4172/2155-9880.1000440) |
| 苏州爱琴 / 丹阳慧创为标准起草单位 | GB/T 44423—2024 前言 |
| 中科搏锐 BRS 采用朗伯比尔 | 医价网 BRS-100 招标参数文档 |
| Prahl 消光系数表 | [omlc.org/spectra/hemoglobin](https://omlc.org/spectra/hemoglobin/summary.html) |
| Matcher 值 | GB 9706.271—2022 附录 BB.3.1 算例引用 |
| MEDPHOT 协议与 32 块二维体模网格 | Pifferi A, et al. *Appl Opt* **44**(11):2104 (2005), [optica.org](https://opg.optica.org/ao/abstract.cfm?uri=AO-44-11-2104) |
| IAD 典型不确定度 μa 4~5% / μs′ 11~12%；NIST 溯源标准件 | *Appl Opt* **54**(19):6118 (2015), [optica.org](https://opg.optica.org/ao/abstract.cfm?uri=ao-54-19-6118) |
| 体模厂家答复（§4.5）及其 IAD 方法 | BestView 邮件答复 2026-08；*J Biophotonics* **19**:e70289 (2026) |

## 附 C：本文数字的来源

除注明引自文献者外，全部为基于 [`tools/srs_reference.py`](tools/srs_reference.py) 正向模型的仿真结果：

- §2.2 权重与噪声、§2.3 波长数对比、§3.1 增益敏感度、§3.2 μs′ 敏感度、§4.3 标定精度 —— 蒙特卡洛，每点 120~1200 次
- §2.4 动态范围、§3.3 浅层抑制、§4.4 折射率与尺寸 —— 解析计算
- §4.2 自标定可行性与静默失败、§4.5 波长容差、§7 ε 表敏感度 —— 3×4 矩阵正向仿真 + 最小二乘反解，每点 6~8 次重复
- §3.2.2 自解谱指数 —— `toi_fit_scattering()` 确定性拟合，可由 `python tools/srs_reference.py` 自检第 5 项复现
- §3.3 的 γ 为参数化演示，**非实测值**，需用实际探头几何标定

⚠️ **全部结果的共同适用边界**：均匀半无限介质 + Farrell-Patterson 稳态扩散解。真实头部为分层结构，§3.2 的自解谱指数在分层几何下**未经验证**。

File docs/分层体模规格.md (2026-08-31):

# 三层分层体模规格（询价用）

**用途**：验证空间分辨光谱（SRS）在分层介质下的行为，标定分层几何带来的增量修正。

**波长**：700 / 730 / 770 / 810 / 850 nm（本设备五波长）

---

## 1. 结构

```
        ┌─────────────────────┐
   ①    │  浅层（头皮+颅骨）    │  8 / 12 / 16 mm  ← 三片，可换
        ├─────────────────────┤
   ②    │  CSF 模拟层          │  0 / 3 mm        ← 两档（含"无"对照）
        ├─────────────────────┤
   ③    │  深层（脑）          │  ≥30 mm，3 档血氧
        └─────────────────────┘
```

**模块化**：①②做成可更换薄片，③沿用 Φ100 × 50 mm 块体。
**10 个物件 → 18 种组合**（3 浅层 × 2 CSF × 3 深层）。

---

## 2. 光学参数

### ① 浅层（头皮 + 颅骨合并）

对应 SO₂ 70%、tHb 50 μM + 水/脂质背景。**降氧过程中不变。**

| λ (nm) | 700 | 730 | 770 | 810 | 850 |
|---|---|---|---|---|---|
| **μa** (cm⁻¹) | 0.1669 | 0.1559 | 0.1757 | 0.1713 | 0.1854 |
| **μs′** (cm⁻¹) | 9.39 | 8.93 | 8.38 | 7.88 | 7.44 |

厚度档位：**8 / 12 / 16 mm**（±0.2 mm）

### ② CSF 模拟层

⭐ **关键是极低散射**——这是"光管效应"的来源，也是本体模最重要的验证对象。

| λ (nm) | 700 | 730 | 770 | 810 | 850 |
|---|---|---|---|---|---|
| **μa** (cm⁻¹) | 0.0250 | 0.0250 | 0.0270 | 0.0290 | 0.0330 |
| **μs′** (cm⁻¹) | **0.34** | **0.33** | **0.31** | **0.30** | **0.28** |

厚度档位：**0（无此层，作对照）/ 3 mm**（±0.2 mm）

⚠️ μs′ ≈ 0.3 cm⁻¹ 比常规体模低 30 倍，**需确认厂商能否做到**。

### ③ 深层（脑），3 档血氧

对应 tHb 75 μM + 0.020 cm⁻¹ 背景，按下式生成：

```
μa(λ) = ln10 × [ε_HbO(λ)·S + ε_HbR(λ)·(1−S)] × 75e-6 + 0.020
```

| λ (nm) | **SO₂ = 40%** | **SO₂ = 70%** | **SO₂ = 90%** | **μs′** (cm⁻¹) |
|---|---|---|---|---|
| 700 | 0.2383 | 0.1654 | 0.1167 | **12.30** |
| 730 | 0.1896 | 0.1488 | 0.1217 | **11.83** |
| 770 | 0.2161 | 0.1786 | 0.1536 | **11.14** |
| 810 | 0.1659 | 0.1719 | 0.1759 | **10.64** |
| 850 | 0.1767 | 0.1931 | 0.2040 | **10.31** |

厚度：**≥30 mm**，横向 **Φ100 mm**

⭐ **μs′ 已更新为成人前额的实测人群均值**（10 人时域 DOS，Zenodo
10.5281/zenodo.15828014，CC-BY 4.0），对应幂律 `μs′ = 10.83·(λ/800)^(−0.932)`。
个体标准差约 ±0.9 cm⁻¹（μs′@810 实测范围 9.1~11.9）。

> 原规格用的是文献典型值 μs′(800)=9.0、b=1.30，实测偏低约 18%。

> **关键特征**：SO₂ 越低，短波端（700/730）μa 越高、长波端（810/850）越低。
> **这个交叉是血红蛋白光谱的特征**，深层三块必须复现这个趋势，否则失去意义。

### 消光系数表（供厂商核算，wray 表，单位 1/(M·cm)）

| λ (nm) | 700 | 730 | 770 | 810 | 850 |
|---|---|---|---|---|---|
| ε_HbO | 419.3 | 510.0 | 701.0 | 914.3 | 1097.0 |
| ε_HbR | 1827.7 | 1296.5 | 1425.0 | 798.7 | 781.0 |

---

## 3. 其他要求

| 项 | 要求 | 理由 |
|---|---|---|
| **折射率** | 各层 **1.42**（与已订均质体模一致） | 层间界面反射最小 |
| 横向尺寸 | **Φ100 mm** | 探头跨度 50 mm，边缘余量 25 mm |
| 总厚度 | 38 ~ 49 mm（组合后） | 深层需满足半无限近似 |
| **每层独立标定** | ⭐ 各层单独给出五波长（或最接近波长）的 μa、μs′ **及标准差** | 厂商已答复可做 |
| 块间相对精度 | **≤1%**（同批测量条件下） | 差分使用时的关键 |
| 表面平整度 | 与探头贴合无可见间隙 | 近距探测器对间隙敏感 |
| μa/μs′ 公差 | **±10%**（绝对值） | 差分使用，绝对值要求不高 |

---

## 4. 需向厂商确认的五条

| # | 问题 | 为什么关键 |
|---|---|---|
| **1** | **能否做 μs′ ≈ 0.3 cm⁻¹ 的低散射层？** | ⭐ 做不到就无法验 CSF 光管效应，三层退化为两层 |
| **2** | **模块化叠放的层间如何处理？** 需要匹配液（甘油/水）吗？空气间隙多厚？ | ⭐ 间隙会引入额外界面反射，破坏分层等效性 |
| 3 | 浅层薄片最薄能做到多少？厚度公差？ | 8 mm 档是否可行 |
| 4 | **固体模拟血液的光谱保真度** —— 五个波长都能对上，还是只能对上几个？ | 深层三块的 SO₂ 特征必须复现 |
| 5 | 各层的均一性指标（数值） | 层内梯度会污染斜率 |

---

## 5. 使用方式：差分测量

⚠️ **本体模用差分方式使用，不依赖其绝对标称值。**

对同一块深层，分别测「裸测」与「加浅层（+CSF）」，取差值 Δ：

```
Δ(层厚) = SO₂读数(分层) − SO₂读数(裸测)
```

**深层 μa 标称偏 10%，Δ 的变化仅 0.029 %O₂** —— 标称误差几乎完全抵消。

这样：
- **绝对基准**由液体降氧体模（真血液 + 血气仪）给出
- **分层增量**由本体模给出

最终修正式：

$$SO_{2,脑}=k\cdot 读数+b+\Delta(层厚)$$

---

## 6. 本体模能回答的三个问题

| # | 问题 | 现状 |
|---|---|---|
| **1** | **`SO₂读 ≈ f·头皮 + (1−f)·脑` 这个线性混合关系成不成立？** | ⭐ **完全未知**。整套两参数修正的逻辑基础 |
| **2** | CSF 光管效应有多大？ | 完全未知 |
| **3** | 对层厚的敏感度 dSO₂/df 是多少？ | 完全未知，决定误差预算 |

第 1 条最关键：**若不成立，两参数修正吸收不干净，需改方案。** 现在花几千块知道，好过人体试验阶段才发现。

---

## 附：参数来源与不确定性

⚠️ **参数来源已分两类**：
- **深层 μs′** —— 成人前额**实测人群均值**（见文末附表）✅
- **浅层、CSF 层的 μa/μs′，以及深层 μa** —— 仍为 NIRS 文献典型值，**非实测**

⚠️ 实测数据只覆盖「整块前额」的等效光学参数，**没有分层拆解**，
   所以浅层/CSF 的值无法由它直接得到。建议下单前按目标人群
   （心胸外科 / 神经重症）再核对一次。

⚠️ **厚度档位（8/12/16 mm 浅层、3 mm CSF）按解剖学典型值定**，覆盖成人范围。若目标人群包含儿童，需另加薄档。

⚠️ 深层的 tHb = 75 μM 与背景 0.020 cm⁻¹ 是为使 μa 落在文献典型脑组织范围（约 0.15~0.24 cm⁻¹）而选的组合，**不是唯一解**。

⚠️ 本规格由 `fnirs_pipeline` 的 wray 消光系数表计算，与设备算法同源。**若将来更换 ε 表，深层的 μa 目标值需重算。**

---

## 附：成人前额的实测光学参数（用于核对）

10 名成人受试者，时域漫射光谱（TD-DOS）实测，前额位置。
**数据来源**：[Zenodo 10.5281/zenodo.15828014](https://zenodo.org/records/15828014)（CC-BY 4.0），
论文 *Scientific Data* (2026) — Pifferi 组，与 MEDPHOT 协议同源。

| λ (nm) | μa 均值 ± 标准差 (cm⁻¹) | μs′ 均值 ± 标准差 (cm⁻¹) |
|---|---|---|
| 700 | 0.1383 ± 0.0194 | 12.30 ± 1.06 |
| 730 | 0.1366 ± 0.0156 | 11.83 ± 0.99 |
| 770 | 0.1471 ± 0.0151 | 11.14 ± 0.93 |
| **810** | **0.1500 ± 0.0133** | **10.64 ± 0.85** |
| 850 | 0.1745 ± 0.0149 | 10.31 ± 0.78 |

**导出量**

| 量 | 实测 |
|---|---|
| μs′ 谱指数 b（逐人） | **0.927 ± 0.191**，范围 **0.538 ~ 1.303** |
| StO₂（由 μa 谱按 wray 表解出） | **71.9 ± 4.5 %**，范围 **66.3 ~ 79.6** |

**三条可直接使用的结论**

1. ⭐ **3×4 均质矩阵的目标区间选对了** —— 实测 μa 0.124~0.172、μs′ 9.1~11.9，
   完全落在拟定的 μa 0.10~0.20 / μs′ 8~12 之内。
2. ⭐ **谱指数 b 的实测下界 0.538** —— `srs.py` 的 `B_BOUNDS` 已据此从 0.5 放宽到 0.4。
3. ⭐ **健康成人前额 StO₂ 的人群跨度是 13 个点**（66.3~79.6）。
   作为对照：《基于近红外光谱的三波长脑组织氧监测系统的研制》（中国医疗器械杂志
   2024, 48(1):26）报告的 13 例志愿者读数，本系统跨 64~69%、对照的 BRS-100B 跨
   64~68% —— **均只有 5 个点，是量程压缩的直接旁证**。

⚠️ 该数据集还含**每位受试者前额的超声图像**，可用于把本规格的层厚档位
（现为解剖学文献典型值）替换为实测分布。**尚未处理。**

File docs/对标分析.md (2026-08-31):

# 对标分析：脑血氧设备技术路线与本项目差距

> 2026-08-14

**核心结论**：竞品与本项目**架构同构**——都是 CW + 五波长 + 单探头多接收器 + MBLL。差距全部是工程实现（距离配置、饱和、采样率、空间分辨反演、标定），**没有一条是路线选错**。

| 角色 | 产品 | 说明 |
|---|---|---|
| **商业对标** | 博联众科 **MOC 系列** | 客户指定对象；功能集最完整 |
| **结构对标** | 博联 **MOC200**、中科搏康 **BRS-100** | MOC200 硬件与本项目完全一致；BRS 多一个接收器 |
| **设计参照** | Artinis **PortaLite MkII** | 唯一公开完整规格（具体距离、通道分类） |

**标注约定**：✅ 有原文出处（见 §6）｜⭕ 推断｜❓ 未找到

---

## 1. 竞品技术路线

### 1.1 已核实事实总表

| 特征 | MOC | BRS-100 | 出处 |
|---|---|---|---|
| 连续光 CW | ✅ | ✅ | — |
| 五波长 | ✅ 五波长 LED 冷光源 | ✅ 五种不同波长近红外 LED | 官网 / 招标参数 |
| 单探头多接收器 | ✅ **2 个**（MOC200） | ✅ **≥3 个** | 官网 / 招标参数 |
| 明确声称空间分辨 | ✅ **"算法为空间分辨率（SRS）"** | ⭕ 由 ≥3 接收器推断 | MOC200 原文 |
| 声称朗伯-比尔为原理 | ✅ | ✅ "算法：朗伯比尔定律" | 两家表述一致 |
| 连续绝对 rSO₂ | ✅ | ✅ | 见 1.3 |
| 报 THI / ΔTHI | ✅ 界面显示 **1.38** | ✅ | — |
| 通道数 | 四通道 | 六通道（开通 ≥四） | — |
| 准确度 | ❓ | ✅ 说明书 **±2%**（50~90%）<br>招标参数 ≤±1.5% | — |
| 采样率 | ❓ | ✅ **≥10 Hz** | — |
| 注册 | ❓ | ✅ 京械注准 20212070585（2021） | — |
| **源探距离** | ❓ | ❓ | ⚠️ 三家全未公开，见 §5 |

### 1.2 MOC400 参数全集 ✅

| 参数 | 官网原文定义 |
|---|---|
| **rSO₂** | 局部脑组织氧饱和度，实时变化的数值 |
| **BL / ΔBL** | 「传感器置于监测部位病人在**平稳生理状态**下的 rSO₂ **初始值**」；ΔBL 为相对初始值的实时变化 |
| ΔO₂Hb / ΔHHb / ΔtHb | 氧合 / 脱氧 / 总血红蛋白浓度变化量 |
| AUC / TUT / AUT | 去饱容积；低于基线的累积时间；该时间占总监测时长的百分比 |
| **VOT** | 血管阻断测试，**自动分阻断/再灌注/恢复区并计算各区灌注速率** |
| **ΔCyt** | 细胞色素氧化酶相对基线的浓度变化，**宣称"业内首创该指标的监测"** |
| THI / ΔTHI | 血红蛋白浓度指数及其变化量 |

其他：三种传感器规格（成人/儿童/新生儿）；波动指数（±20% 绿 / ±30% 黄 / ±40% 红）；**适应症含急诊 ECPR、急性颅脑损伤、中毒**。

### 1.3 共同架构：SRS + MBLL 双通路 ⭕

```
多波长光强
   │
   ├─→ 空间分辨通路（多距离）
   │     解 μa(λ)（带未知缩放 k）
   │       ├─→ rSO₂ = C_HbO/(C_HbO+C_HbR)   k 约掉 → 绝对值
   │       └─→ THI  = k·(C_HbO+C_HbR)        k 保留 → 只能叫"指数"
   │
   └─→ MBLL 通路（微分）
         ΔOD → ΔO₂Hb、ΔHHb、ΔtHb（MOC 另加 ΔCyt）

BL/ΔBL、AUC/TUT/AUT、VOT 建立在 rSO₂ 之上
```

**"以修正朗伯-比尔定律为基本原理"描述的是 MBLL 通路**，也是最易向非专业读者解释的一条；rSO₂ 走的是另一条。

**参数集与 Hamamatsu NIRO-200NX 一一对应**（NIRO 的 TOI 由 SRS 算、Δ 量由 MBLL 算 ✅）：

| NIRO-200NX | MOC | BRS-100 |
|---|---|---|
| TOI | rSO₂ | 脑血氧饱和度 |
| THI / nTHI | THI / ΔTHI | THI |
| ΔHbO₂ / ΔHHb / ΔTHb | ΔO₂Hb / ΔHHb / ΔtHb | CHbO₂ / CHb / CtHb |

连命名习惯都一致（用 O₂Hb / HHb 而非更常见的 HbO / HbR）。

#### 支撑"rSO₂ 为连续绝对量"的证据

**BRS-100 说明书 3.4.2** ✅：

> 「开始监测后，**系统会自动计算基线**，监测过程中可点击基线校准按钮**重新校准基线**。**基线值在波形图中以虚线表示**。」

基线由系统自动计算、可随时重校、以虚线叠加显示——说明它只是一条参考线，rSO₂ 曲线独立存在。配合 BRS 的**绝对阈值报警**（高 85% / 低 55%）与 MOC 的**急诊适应症**（心脏骤停患者无"平稳生理状态"可取基线），三者互相印证。

### 1.4 三个技术要点

#### ① 绝对**浓度**与绝对**饱和度**是两回事

绝对衰减写全：

```
A(λ) = μa(λ)·L(λ) + G(λ)
       ↑          ↑        ↑
    想要的    未知光程   未知散射损失
```

微分测量 `ΔA(λ) = Δμa(λ)·L(λ)` 中 `G` 消失但 `L` 仍在，故只能得 `Δc·L`。

**但饱和度是比值**，`C_HbO` 与 `C_HbR` 的公共缩放误差在比值中约掉，因此对 `L` 的绝对值不敏感：

| 目标量 | CW 单距离能否得到 |
|---|---|
| Δc·L | ✅ 直接，无需标定 |
| **绝对饱和度 StO₂ (%)** | **⚠️ 可以**，需靠假设或经验标定约束 L(λ)、G(λ) |
| 绝对浓度 μM | ❌ 需多距离 / 频域 / 时域 |

> **类比脉搏血氧**：SpO₂ 设备同样宣称基于比尔-朗伯，但 `R → SpO₂` 对照表完全由人体去氧试验拟合（ISO 80601-2-61 要求人体试验）。**"以 MBLL 为原理"与"需要人体标定"不矛盾——前者是正向模型，后者是反演的最后一公里。**

#### ② 只有 2 个点时，"差值"与"斜率"是同一个运算

MOC200 称「评估**两个接收器光强的差异**」，同时又称算法为 SRS——两者不矛盾：

```
斜率 = (A₂ − A₁) / (ρ₂ − ρ₁)      Δρ 是常数 → 斜率 ∝ 差值
```

分野不在算术，而在如何解释这个差值：**代入扩散模型解 μa（SRS）**，还是**直接查标定曲线（经验减法，INVOS 式）**。

**因此 2 接收器 + 5 波长在数学上是完整的**，rSO₂ 与 THI 都能出。代价见 §3.4。

#### ③ 五波长的用途是补偿个体差异，不是解更多色团

**MOC200 原文** ✅：

> 「与五个波长光源组合，可以形成**多耦合光路**，降低不同患者**肤色、颅骨密度差异、皮下组织厚度**的差异性对数据精度影响。」

这构成一条清晰的设计哲学——**用波长多样性替代距离多样性**：

| 补偿手段 | 代表 |
|---|---|
| 增加波长（5 波长 × 2 接收器 = 10 条光路） | **MOC200 = 本项目** |
| 增加距离（2 波长 × 3 距离 = 6 条） | PortaLite |
| 两者都增加（5 × ≥3 = ≥15 条） | BRS |

### 1.5 MOC 与 BRS 的差异

| 项目 | MOC | BRS-100 |
|---|---|---|
| **Cyt** | ✅ 有，"业内首创" | ❌ 无 |
| **VOT 模式** | ✅ 内置，自动分区算灌注速率 | ❌ 仅 Mark 点标记 |
| 接收器数 | 2（MOC200） | **≥3** |
| 产品范围 | 专注脑氧 | 脑氧 + 组织氧 + **脉搏血氧** |
| 无线探头 | 未见 | ✅ 无线脑血氧头带 |
| 信号质量指示 | ⭕ 七种传感器状态提示（MOC200） | ✅ 五级信号质量显示 |

> ⚠️ **关于 Cyt 的方法学提醒（对本项目同样适用）**：oxCCO 的主流测量手段是**宽带 NIRS 而非离散波长** ✅——其差分-氧化还原吸收峰宽而平缓，需连续光谱才能与血红蛋白可靠分离（代表系统 MAESTROS 为时域、2bNIRS 为 780–900 nm 宽带）。MOC 与本项目均用五个离散波长报 Cyt，方法学上偏激进；若对外声称 Cyt 定量准确性，需额外验证证据。**BRS 有五波长却不报 Cyt，可能正是出于这一顾虑。**

---

## 2. 与本项目的差距

### 2.1 硬件架构对照

| 维度 | **本项目** | **MOC200** | **BRS-100** | PortaLite MkII |
|---|---|---|---|---|
| 波长数 | 5 | **5** ✅ | **5** ✅ | 2 ❌ |
| 光源架构 | 1 组多波长 | **1 组** ✅ | **1 组** ✅ | 3 个位置 ❌ |
| **接收器数** | **2** | **2** ✅ **一致** | ≥3 | 2 |
| **光路数** | 5×2 = **10** | 5×2 = **10** ✅ | ≥15 | 2×3 = 6 |
| 集成形态 | 一体贴片 | 一体贴片 ✅ | 一体探头 ✅ | 一体贴片 |
| 源探距离 | **10 / 30 mm** | ❓ | ❓ | 29/35/41 + 短距 7.2/8.0 |
| 空间分辨解 μa | ❌ | ✅ | ✅ | ✅ |
| 连续绝对 rSO₂ | ❌ 基线为用户输入 | ✅ | ✅ | ✅（TSI） |
| THI | ⚠️ 同名但为摩尔量 | ✅ 无量纲指数 | ✅ | ✅ |
| Cyt | ✅ | ✅（MOC400） | ❌ | ❌ |
| AUC/TUT/AUT、VOT | ❌ | ✅ | AUC ✅ | ❌ |
| 采样率 | **1 Hz** | ❓ | **≥10 Hz** | 100 Hz |
| 数据接口 | TCP/JSON 全量原始数据 | 电脑端 APP | USB/RS-232/VGA/RJ-45 | — |

> ⭐ **本项目与 MOC200 的硬件配置完全一致**：1 组五波长 LED + 2 个接收器 + 同一贴片 + 10 条光路。**唯一未知的硬件差异是源探距离配置**，而这恰是最容易改的一项（改探头版图，不加器件、不影响采样率）。

**PortaLite 只有 2 个波长**，这决定了它的时分复用压力与"加光源位置"的选择——**均不适用于本项目**，故只作设计参照。

### 2.2 三个必须正视的实测差距

**① 主输出通道当前在输出噪声**（实测 `result_table/2026-07-16_15-52-29` ch2）

| 通道 | 光强 std/mean | ΔHbO rms |
|---|---|---|
| `S1_D1`（长距 30 mm） | **0.00043** | 1.8e-9 M |
| `S1_D1_ssr`（默认输出） | — | **2.8e-9 M ≈ 0.003 μM** |
| `S1_D2`（短距 10 mm） | 0.38 | 2.6e-5 M ≈ 26 μM |

长距撞顶 → SSR 的 β ≈ 0 → 校正量 ≈ 0 → 输出 ≈ 量化噪声。生理信号量级是几十 μM·cm。**此条不修，其余对比均无意义。**

**② 采样率差一个数量级**：1 Hz vs ≥10 Hz。GB/T 44423 要求全通道 ≥10 Hz。

**③ `thi` 不只是命名问题**：本项目 `thi = HbO_abs + HbR_abs`（由假设基线凑出的摩尔量）与行业 THI（由 μa 推出的无量纲指数）**不是同一物理量**。THI 必须从空间分辨通路得到。

### 2.3 核心结论：差距全是工程实现

**MOC200 用与本项目完全相同的硬件配置；BRS 只多一个接收器，且于 2021 年取得注册证、声称 ±2%、运行 ≥10 Hz。**

| 差距 | 性质 | 涉及架构变更 |
|---|---|---|
| 源探距离配置不当（10 mm 太浅） | 硬件，改探头版图 | ❌ |
| 长距饱和、无分探测器增益 | 硬件/固件 | ❌ |
| 采样率 1 Hz | 固件时序 | ❌ |
| 无空间分辨反演 | 软件 | ❌ |
| 无绝对衰减标定 | 工艺 | ❌ |
| 无准确度标定 | 标定/临床 | ❌ |
| （追平 BRS）少 1 个接收器 | 硬件，可选 | ❌ |

**没有一条是"路线选错了"。全部为把已有骨架补完整的工程工作。**

---

## 3. 改造方案

### 3.1 ⭐ 三档方案对比

| | **方案一：只挪位置** | **方案二：加 1 路** | **方案三：加 2 路** |
|---|---|---|---|
| 硬件改动 | **仅改探头版图**，不加器件 | +1 路 PD/TIA/ADC | +2 路 |
| 接收器 | 2 | 3 | 4 |
| 距离 | 约 20 / 30 mm | 10 / 30 / 40 mm | 10 / 30 / 35 / 40 mm |
| 对标 | **MOC200**（硬件一致） | INVOS 式 | BRS / NIRO / PortaLite 式 |
| 空间分辨点数 | 2 | 2（另留超短距做 SSR） | **3** |
| 能出 rSO₂ / THI | ✅ / ✅ | ✅ / ✅ | ✅ / ✅ |
| **拟合残差可诊断** | ❌ | ❌ | ✅ |
| 保留超短距 SSR | ❌ 牺牲 | ✅ | ✅ |
| 采样率影响 | 无 | 无 | 无 |
| 成本 | **最低** | 低 | 中 |

**选择依据**：若确认 MOC200 两个距离都在 20~40 mm 区间 → **方案一**成本最低且有商业产品验证；若要保留超短距 SSR（本项目现有差异化功能）→ 方案二起步；若要在开发阶段能自查 → 方案三。

> ⚠️ **方案一的前提是拿到 MOC200 的实际距离**（见 §5）。在此之前不要盲目挪——挪错了既丢 SSR，又换不来有效的空间分辨。

### 3.2 ⭐ 若要增加点数：加探测器，不加光源位置

由光学互易性，多距离可用**多光源位置 + 单探测器**（PortaLite）或**单光源 + 多探测器**（NIRO、INVOS、BRS）实现。两者数学等价，但**对五波长系统代价差别极大**。

**关键事实：探测器并行采样。** 本项目原始数据中两个探测器共用同一时间戳：

```
Time      DetectorId  Wavelength  Value
0.698974      1           2       6620836   ← S1_D1
0.698974      2           2        914534   ← S1_D2
```

| | 加光源位置 | **加探测器** |
|---|---|---|
| 时分轮转组数 | 5 → 15（×3） | **不变** |
| **有效采样率** | 1 Hz → **0.33 Hz** | **不受影响** |
| 需要增加 | 一整组 5 波长 LED + 驱动 | 1 路 PD + TIA + ADC |
| 配对键数 | 10 → 30 | 10 → **20** |

**PortaLite 加光源位置，是因为它只有 2 个波长**（3 位置 × 2 波长 = 6 组，仍跑 100 Hz）。本项目五波长，加位置的时分代价是它的 2.5 倍。**BRS 同为五波长系统，选择的正是"1 组光源 + ≥3 接收器"。**

### 3.3 几何设计要点

**① 短距通道与 SRS 距离是两组独立的东西**

PortaLite 的两组距离完全分开 ✅：

| 用途 | 距离 | 作用 |
|---|---|---|
| **短距通道** | **7.2 / 8.0 mm** | 只看浅层，用于头皮干扰抑制 |
| **SRS 距离** | **29 / 35 / 41 mm** | 紧密排布的远距离，拟合斜率出 TSI |

**短距不参与 SRS 斜率计算**，且它把短距做得比本项目的 10 mm 还短，正是为让其纯粹只采样浅层。

> **本项目的 10 mm 短距不能当 SRS 的第二个点**——10 mm 基本只走头皮，30 mm 含深层，两点跨越不同组织层，违反 SRS 的均匀半无限介质假设。**不是"点数不够"，是"点选错了"。**

**② 每个波长必须在所有距离上都有测量值**

PortaLite 规格原文是「3 LEDs, **each with 2 wavelengths**」——3 个位置各发全部 2 个波长。因为：

```
对波长 λ：  A(λ, ρ₁)  A(λ, ρ₂)  A(λ, ρ₃)  →  拟合 ∂A/∂ρ  →  μa(λ)
```

若各位置发不同波长，每个波长只剩一个距离点，斜率无从谈起。**波长维度与距离维度正交。**

**③ 建议几何**

```
[光源]──7~10mm──[PD短]────────30mm────────[PD1]──5mm──[PD2]──5mm──[PD3]
  5波长                                    └──────── SRS 三点 ────────┘
                                                 30 / 35 / 40 mm
```

**参考锚点**：INVOS 用 30/40 mm，PortaLite 用 29/35/41 mm，成人脑氧商用设备普遍在 30~40 mm 区间。

### 3.4 ⚠️ 加探测器带来的三个新约束

**① 探测器间增益一致性成为关键**

这是加探测器相对加光源的唯一劣势，两者对称：

- 加光源：各位置共用同一 PD → PD 增益约掉，但**LED 位置间输出功率差**偏移斜率
- 加探测器：共用同一光源 → 光源功率约掉，但**探测器间响应度/TIA 增益差**偏移斜率

**必须在体模上做探测器间增益标定**（见 §4.1④）。好处是 PD + TIA 的长期漂移通常小于 LED 输出漂移。

**② 各探测器需独立增益档位**

衰减随距离近似指数上升，30→40 mm 可能掉一个数量级以上：`10mm 最亮 ── 30mm 中 ── 40mm 最暗`。

**三个探测器不能共用一档增益。** 本项目当前长距撞顶，本质上就是没有分别配增益——**修饱和时应顺手把"每探测器独立增益"的架构做进去**。

**③ 光学串扰**

探测器数量增加、间距变近，探头基板内漏光风险上升，需做光学隔离。GB 9706.271 **201.12.1.101.9 信号串扰**（XT = 20·log₁₀|V₀/V|）正是测这个，且该条要求**按正常使用排列**测试——一体式探头可直接执行，无需工装。

**④ 2 点与 3 点的取舍**

2 点数学上够拟合斜率（即 INVOS 几何），但：

| | 2 点 | 3 点 |
|---|---|---|
| 能算斜率 | ✅ | ✅ |
| **能检验扩散模型是否成立** | ❌ 残差恒为零 | ✅ 看拟合残差 |
| 单个探测器耦合异常 | **无法察觉，直接扭曲斜率** | 残差会暴露 |

第三个点买到的是"可检验性"。**但 3 点也不能自动标定增益**——3 点 + 3 个未知增益偏置 + 1 个斜率 = 4 未知数 3 方程，仍欠定，残差只能告诉你"不对劲"。

### 3.5 完整待办清单

| # | 事项 | 说明 |
|---|---|---|
| 1 | **修长距饱和 + 每探测器独立增益** | 前置条件。不要只调全局增益，直接做成分探测器可配 |
| 2 | **确定并实施新几何** | 按 §3.1 选档；保留短距用途不变，可缩至 7~8 mm |
| 3 | **PD 间光学隔离** | 可用 201.12.1.101.9 验证 |
| 4 | **提高采样率** | 目标 ≥10 Hz。**加探测器方案下与几何改动解耦，可分开推进** |
| 5 | **协议与配对扩展** | `DetectorId` 为 payload byte1，现用 0x01/0x02，扩至 0x03/0x04 **协议完全兼容**；`config.DETECTOR_CHANNELS` 加行；配对由 2×5=10 键改为 4×5=20 键（改 `aggregate_wavelength_cycles` 的 `required_keys`）。**均为配置级改动** |
| 6 | **保留 MBLL 通路不变** | Δ 浓度量与 Cyt 仍由 MBLL 出，DPF 继续用现有 `get_dpf()`。加 SRS 是**并联新通路**，不是替换 |
| 7 | **SRS 反演模块** | 见 §4.1 |
| 8 | **THI 重新定义** | 改为由 μa 推出的无量纲指数 |
| 9 | **区分相对/绝对通道的数据结构** | 参照 PortaLite「6 relative, 1 absolute」，输出中明确标注 |
| 10 | **补齐 AUC / TUT / AUT / VOT 分区** | 纯软件，现有数据够算，**投入产出比最高的一块** |
| 11 | **硬件级标定** | 见 §4.1 |
| 12 | **人体准确度标定** | 见 §4.2。**若只声称相对量可跳过** |

> **第 12 项决定投入量级**：做到第 11 步即得一台"带 SRS 硬件但只声称相对量"的设备，可按 GB 9706.271 送检；要声称绝对 rSO₂ 才进入 GB 9706.285 范畴。
>
> **可分两期：先把硬件做到位，标定留待后续——探头只开一次模。**

---

## 4. 标定

### 4.1 硬件级标定（出厂／工厂）

目的：把原始电压转换成与组织光学参数相关的量，消除器件个体差异，保证台间与探头间一致性。

| 步骤 | 内容 | 方法与依据 |
|---|---|---|
| **① 光源参数** | 每个发射探头、每个波长的**峰值波长、FWHM、平均光功率** | **功率计**测光功率、**分光光度计/光谱分析仪**测波长与 FWHM，**直接对着发射探头测**，不经过体模。脉冲输出用 `P_av = P_peak × τ × f`。须在 GB 7247.1 皮肤 MPE 限值内<br>*GB 9706.271 201.12.1.101.2/.3/.4，图 201.102、201.103* |
| **② 探测器暗电流** | 完全遮光下记录各探测器暗电压 | — |
| **③ 探测器响应度** | 已知光强照射，测响应度（V/μW） | — |
| **④ 探测器间增益一致性** | 均匀体模上标定各探测器增益系数 | ⭐ **2 接收器架构的命门**（见 §3.4①） |
| **⑤ 绝对衰减基准** | 已知光学性质的体模上定出绝对基准，折算未知的入射光强与散射损失 | 微分测量不需要，绝对测量必需 |
| **⑥ μa 覆盖标定** | **3~5 组不同 μa** 的标准体模，建立反演关系并检验线性度 | *GB/T 44423 7.4.6：R² ≥ 0.95，浓度跨度 ≥15 dB* |
| **⑦ 出厂一致性校验** | 同一标准体模测所有出厂探头，超差返工 | *GB/T 44423 7.4.7：U = (1−σ/μ)×100% ≥ 90%* |

#### SRS 反演的数学形式

半无限均匀介质的漫反射在扩散近似下满足 `R(ρ) ∝ (1/ρ²)·exp(−μeff·ρ)`，取 `A = −log₁₀R` 后 `∂A/∂ρ = (1/ln10)·[μeff + 2/ρ]`。由此反解：

```
① 测斜率      S = [A(ρ_far) − A(ρ_near)] / (ρ_far − ρ_near)     单位 OD/cm
② 扣几何项    μeff = ln(10)·S − 2/ρ̄                            ρ̄ 取有效距离
③ 解吸收系数  μa = μeff² / (3·μs′)                              ← 平方关系
④ 散射假设    μs′(λ) = a·λ^(−b)                                 ← Mie 幂律，须假设
⑤ 色团分解    由多波长 μa(λ) 解 C_HbO、C_HbR
⑥ 输出        rSO₂ = C_HbO/(C_HbO+C_HbR)    THI = k·(C_HbO+C_HbR)
```

三点须注意：**μa 与斜率是平方关系**；**`2/ρ` 几何项必须扣除**（仅 2 点时 ρ̄ 取有效距离）；具体系数随所采用的扩散模型与边界条件而异，实施前须固定一套模型并在体模上验证。

> **术语**：约化的是**散射**系数 μs′（reduced scattering coefficient）；吸收系数即 μa。

#### 两条通路的标定对象不同

| 通路 | 需要什么 | 本项目现状 |
|---|---|---|
| **MBLL（微分）** | **DPF(λ, 年龄)**，把 Δc·L 换算为 Δc | ✅ 已有：`mbll_core.py` 的 `get_dpf()`（Scholkmann & Wolf 公式） |
| **SRS（空间分辨）** | **μs′ 幂律参数 a、b**；**不经过光程，不需要 DPF** | ❌ 无 |

### 4.2 人体标定（型式标定，一次性）

硬件标定给出的是组织光学参数；**从光学量到临床 rSO₂ 之间的系统偏差**（动静脉加权与金标准定义的差异、颅外污染、部分容积效应、μs′ 假设误差）只能由人体在体实验校正。

#### 流程（GB 9706.285—20XX 立项稿 201.12.1.101.2）

| 步骤 | 内容 |
|---|---|
| **① 受试者** | 健康志愿者；须披露人群的解剖学、生理学与病理生理学范围，以及**肤色、年龄、性别**构成（201.12.1.101.4） |
| **② 置管** | 桡动脉（取 SaO₂）+ 颈内静脉逆行置管至**颈静脉球部**（取 SjvO₂） |
| **③ 受控降氧** | 混合气逐级降低 FiO₂，设多个稳定平台，覆盖**整个声称范围（下限上偏 3%、上限下偏 3%）**，各平台数据点密度相当 |
| **④ 同步采样** | 每个平台同时记录设备读数与动脉、颈静脉血样 |
| **⑤ 参考值** | **一氧化碳-血气分析仪（Co-oximeter）**分析。分析仪性能须优于所抽血样范围 1%（1 SD）或更好 |

#### 参考真值与准确度指标

```
SavO₂ = R · SaO₂ + (1 − R) · SjvO₂
```

- `R` = 动脉血分数，取自**探头下方脑组织的动静脉血量假设比**；行业常用 R = 0.25~0.30
- ⚠️ **强制要求在使用说明书中披露所采用的 R**（201.12.1.101.3 c) 2）

| 指标 | 要求 |
|---|---|
| **StO₂ 准确度** | 设备测量值与参考值之差的**均方根（Arms）**；50%~85% 范围内 **Arms ≤ 10% StO₂** |
| 趋势准确度 | 可选。⚠️ 标准原文：「在撰写本文件时，**未就趋势准确度的报告方法达成共识**」 |
| 须提供的图表 | rSO₂ 对 SR 的**散点图**（含网格线与 y=x 一致度线）及回归参数、**Bland-Altman 图**、总体平均偏差 μ₀、受试者间/内方差、95% 一致性限值 |
| 说明书须注明 | 因测量值呈统计概率分布，**约 2/3 落在 Co-oximeter 值的 ±Arms 之内** |

> **人体标定是一次性型式标定，不是逐台标定。** 最终参数（R、消光系数、散射假设）写入固件，量产设备只做硬件级出厂一致性校验（§4.1⑦）。
>
> ⚠️ **小儿患者的准确度不能由成人受控降氧研究支持**，须另行针对预期人群做便利样本研究（201.12.1.101.2 d）。

### 4.3 ⭐ 法规门槛可能低于预期

BRS-100 说明书对**脉搏血氧**的准确度来源有完整披露（ISO 80601-2-61 强制内容）✅：

> 「**功能测试仪不能用于评价脉搏血氧探头和脉搏血氧监护仪的准确度。**」
> 「建立指脉血氧饱和度准确度声称的测试方法总结：利用**反射式指脉氧模拟仪**……」

**而脑血氧与组织血氧的 ±2% 是如何建立的，说明书只字未提。**

| 观察 | ⭕ 推断 |
|---|---|
| 仅 SpO₂ 披露标定来源 | SpO₂ 有强制专用标准要求披露；脑血氧在 2021 年注册时无专用标准，无披露义务 |
| 用「**允差 ±2%**」而非 **Arms** | 计量学示值误差口径，非临床统计口径。±2% 远严于 GB 9706.285 的 Arms ≤10%，也远严于国际同类的 ±4~6%。**对着人体血气做出的 Arms 不可能是 ±2%** |

**BRS-100 于 2021 年取得注册证，当时 GB 9706.285 尚不存在（至今仍为立项稿）。**

> ⚠️ **优先级高于任何技术改造的三件事**：
> 1. 当前（2026 年）注册脑血氧仪，药监**实际要求**的准确度验证方式
> 2. GB 9706.285 的**实施时间表**——若在注册周期内落地，按旧口径的准备会作废
> 3. BRS-100 注册时**实际提交了什么资料**（说明书未写 ≠ 未做）
>
> 应向注册咨询机构或承检机构直接确认。

---

## 5. 待确认事项

| # | 待确认 | 为什么重要 |
|---|---|---|
| 1 | ⭐⭐ **MOC200 / BRS 的实际源探距离** | **唯一阻碍直接照搬的信息**。它把"要不要加器件"这个决策直接定死（§3.1）。途径：实物探头测量、产品技术要求、代理商技术资料 |
| 2 | ⭐ **rSO₂ 准确度指标（Arms）与声称范围** | 对标基准，也是自己定指标的锚点 |
| 3 | **MOC400 是否比 MOC200 增加了接收器** | 其增量参数（Cyt/THI/VOT/AUC）**均可在 2 接收器上实现**，故推不出来。两型号差异可能主要是软件档次 |
| 4 | 说明书披露的**动静脉间室比 R** | GB 9706.285 强制披露项，可反推标定方法 |
| 5 | 三家五个波长的**具体值** | 与本项目 850/810/770/730/700 是否一致 |
| 6 | MOC 是否有短距通道 / 头皮干扰抑制 | 决定本项目 SSR 是否为真差异点 |
| 7 | 定价 | 若走跟随路线，核心竞争参数 |
| 8 | ChiCTR2100052321 是否真实存在 | 若为真，是一份国产脑氧仪完整临床验证方案与实测指标。**须在 [chictr.org.cn](https://www.chictr.org.cn/searchproj.html) 直接检索核实后方可引用** |

> **第 2~5、7 项大多能从 NMPA 注册数据库的产品技术要求一次性拿到**，且是厂商自己承诺的指标，比宣传资料可靠。

---

## 6. 来源

### 已核实（✅）

| 内容 | 出处 |
|---|---|
| MOC400 参数定义、VOT、Cyt 首创声明、传感器规格、界面读数（THI 1.38）、适应症含 ECPR | 项目方保存的 MOC400 官网页面配图 |
| MOC100 原理表述、五波长传感器、四通道、校准说明 | 项目方保存的 MOC100 官网页面（`blztech.cn/Products-37732121.html`） |
| **MOC200：算法明确为 SRS、通过两个接收器光强差异评估氧饱和度、五波长 LED 冷光源、一个传感器上两个接收器、五波长用于降低肤色/颅骨密度/皮下厚度差异、七种传感器状态提示** | MOC200 产品介绍文章（项目方提供） |
| BRS-100 性能指标、基线机制、报警限值、SpO₂ 标定方法、注册号、通道配置 | 《BRS-100 无创脑血氧监护仪使用说明书 V1.5》（2023-05），中科搏康（北京）医疗器械有限公司 |
| **BRS-100 五波长、单探头接收器 ≥3、算法为朗伯比尔定律、误差 ≤±1.5%、五级信号质量、≥11 种报警、探头独立注册证** | 招标参数文件《中科博瑞设备参数-算法朗伯比尔定律》（医价网）⚠️ 性质见附 A |
| NIRO-200NX：TOI 由 SRS 算、THI/nTHI 定义、四波长（775/825/850/905）、多探测器置于单一探头内 | [Hamamatsu NIRO 资料](https://www.pubcompare.ai/product/VCziCZIBPBHhf-iFbZU1/)、[Neupsy Key](https://neupsykey.com/near-infrared-spectroscopy-2/) |
| PortaLite MkII 全部规格 | 《PortaLite MKII Leaflet》rev. 2305 v1.1（©2023 Artinis）—— [PDF](https://neurolite.ch/sites/default/files/PortaLite_MKII_Leaflet_Neurolite_2023.pdf)、[官方页面](https://artinis.com/portalite) |
| oxCCO 主流用宽带 NIRS；MAESTROS（时域）、2bNIRS（780–900 nm 宽带多距离） | [MAESTROS (PMC6054019)](https://ncbi.nlm.nih.gov/pmc/articles/PMC6054019)、[2bNIRS (arXiv 2512.04787)](https://arxiv.org/pdf/2512.04787) |
| EQUANOX 三波长（730/810/880）、双发射源；INVOS/EQUANOX 被评为趋势设备，FORE-SIGHT 可测绝对值 | [Cerebral oximetry in cardiac and major vascular surgery (PMC3484590)](https://pmc.ncbi.nlm.nih.gov/articles/PMC3484590/) |

### 标准依据

| 内容 | 出处 |
|---|---|
| Δμa 与 L 不可分离、Δc·L 为 CW 官方测量量 | GB 9706.271—2022 附录 BB.2 |
| 光源参数测试方法（功率计/光谱仪、脉冲 P_av 公式、MPE 限值）；信号串扰 XT | GB 9706.271—2022 201.12.1.101.2/.3/.4、.9，图 201.102、201.103 |
| StO₂ 准确度 Arms ≤10%、SavO₂ 定义、须披露 R、删除体模法、受控降氧研究完整要求、小儿不能由成人研究支持 | GB 9706.285—20XX（立项稿）201.3.220、201.12.1.101.1~.4 |
| 全通道时间分辨率 ≥10 Hz；线性度 R²≥0.95；探头响应一致性 U≥90% | GB/T 44423—2024 6.3.1、7.4.6、7.4.7 |
| SpO₂ 须经人体试验标定 | ISO 80601-2-61 |

### 本项目

| 内容 | 出处 |
|---|---|
| 长距饱和（std/mean = 0.00043）、`S1_D1_ssr` rms 0.003 μM、采样率 1 Hz、探测器同时间戳 | `result_table/2026-07-16_15-52-29`，ch2 |
| DPF 公式（Scholkmann & Wolf） | `fnirs_pipeline/mbll_core.py` 的 `get_dpf()` |

---

## 附 A：招标参数文件的性质

⚠️ 《中科博瑞设备参数》为**医院采购招标的技术参数文件**，非厂商规格书：

- 招标参数常按目标产品"量身定制"，**结构性描述（五波长、接收器 ≥3、朗伯比尔定律）可信度较高**
- 但采购方可能加码，**数值型指标应打折看**——其误差 ≤±1.5% 严于说明书的 ±2%，**以说明书为准**
- 带 ▲ 为实质性条款（参数同屏显示、六通道、误差与精度）
- 公司名"中科**博瑞**"与说明书"中科**搏康**"不一致，但参数列表（六通道、无线头带、组织氧探头、THI/ΔTHI/BL/ΔBL/AUC/AUT/TUT）与 BRS-100 高度吻合，**判定为同一产品**

## 附 B：推断置信度

| 推断 | 依据 | 置信度 |
|---|---|---|
| 两家均做空间分辨处理 | MOC200 原文点名 SRS ✅；BRS 接收器 ≥3 ✅ | **已证实** |
| 架构为"单光源 + 单探头内多接收器" | 两家原文 ✅ | **已证实** |
| MOC200 = 2 接收器；BRS = ≥3 接收器 | 原文 ✅ | **已证实** |
| 五波长用于补偿个体差异而非解 Cyt | MOC200 原文 ✅ | **已证实（MOC）** |
| rSO₂ 为连续绝对量 | BRS 基线机制 + 绝对阈值报警 + MOC 急诊适应症 | 高 |
| SRS + MBLL 双通路 | 参数集与 NIRO-200NX 一一对应；MOC200 同时点名 SRS 与朗伯比尔 | 高 |
| 两家均解出 μa | 均报 THI；2 点亦可解出 μa | 高 |
| BRS 的 ±2% 非人体研究所得 | 口径为允差非 Arms；远严于国际同类；未披露来源 | 中 |
| MOC400 相对 MOC200 增加了接收器 | 无证据；其增量参数均可在 2 接收器上实现 | **低** |
| MOC 成人款距离为 2 / 3 cm | 第三方 AI 基于"同团队论文"的推断；论文与专利均未能核实，且该论文为三波长（660/750/880）与 MOC 五波长不符 | **很低，不采信** |

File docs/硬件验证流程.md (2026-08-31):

# 硬件验证流程

**对象**：双通道五波长 fNIRS 设备（S1_D1 @3.0 cm、S1_D2 @1.0 cm，850/810/770/730/700 nm）

---

## 这份文件能回答什么

| ✅ 能回答 | ❌ 不能回答 |
|---|---|
| 探头有没有漏光 | 设备测得准不准（要变孔径体模，见 `检验方法.md`） |
| 读数是多少瓦（可溯源） | 换一种组织／肤色还准不准 |
| 五个波长的响应差多少 | 上真人能不能用 |
| 长时间会不会漂 | 用一年会不会变 |
| 反复贴合稳不稳 | 整个量程都线性吗 |

⚠️ **这是一道准入门槛，不是合格证。** 全部通过只说明「这些毛病不存在」，不说明「没有毛病」。

---

## 三个阶段

| 阶段 | 何时 | 需要什么 |
|---|---|---|
| **阶段 0** | **立即** | 什么都不用买 |
| 阶段 1 | 体模到货（约 4 周） | 体模 + **校准功率计** + 定位工装 |
| 阶段 2 | 可选 | 中性密度滤片 |

**全程记录原始 ADC 值**（每个 探测器 × 波长），不是 HbO/HbR。

---

# 阶段 0：现在就能做

> ⚠️ `config.py` 记录长距 S1_D1 当前**饱和**（「对空气也满值，信息为零」）。
> 这意味着真正看脑的那一路没在输出有效信息。**这一阶段优先级高于一切。**

## T0.1 暗电平

**在问什么**：LED 全关时，电路自己有多少读数？这是后面所有测量的扣除基准。

**怎么做**：LED 全灭 → 探头盖黑布 → 连续采 60 秒。

**看什么**：均值 `D`、标准差 `σ_D`

| 结果 | 结论 |
|---|---|
| `D` < 1% 满量程 | ✅ 正常 |
| `D` 接近满量程 | ❌ **电路问题**（偏置／自激／TIA 饱和），停下来查电路 |

## T0.2 光学串扰 ⭐ 最要紧

**在问什么**：探测器收到的光，有没有一部分是从探头内部直接漏过来的、根本没经过被测物？

**怎么做**：三个状态，LED 逐波长点亮

| # | 状态 | 记为 |
|---|---|---|
| 1 | LED 全灭 | `D` |
| 2 | 探头悬空，正对空旷 | `A_air` |
| 3 | 探头紧贴**黑绒布**（消光材料） | `A_black` |

**看什么**

| `A_black` vs `D` | `A_air` vs `A_black` | 结论 | 怎么办 |
|---|---|---|---|
| 差不多 | 差不多 | ✅ 没有串扰 | 饱和是增益设高了，调档 |
| **明显更高** | — | ❌ **探头内部漏光** | 做光学隔离 |
| 差不多 | 明显更高 | ⚠️ 环境光钻进来了 | 改进遮光 |
| 都接近满量程 | — | ❌ 电路问题 | 查电路 |

> 黑绒布这一步是关键——它把「内部漏光」和「环境光」分开了。只测暗电平和对空气，这两者分不出来。

**判据**：串扰 **< 2%** 于最暗通道的读数

| 串扰占比 | ΔA 误差 |
|---|---|
| 1% | 0.68% |
| **2%** | **1.35%** |
| 5% | 3.31% |

⚠️ 串扰对**真实脑激活**（信号很小）的相对影响，和对大信号**一样**——它压缩比值，不因信号小而放大。不能想着"反正我信号小，无所谓"。

> 对应标准：`GB 9706.271 201.12.1.101.9 信号串扰`

## T0.3 增益档现状

**在问什么**：固件能不能给每个探测器**单独**设增益？

**看什么**

现在 1 cm 和 3 cm 的光强差 **27.6 dB（570 倍）**。共用一档必然一头饱和、一头埋进噪声。

| 现状 | 结论 |
|---|---|
| 支持每探测器独立设 | ✅ |
| 只有全局一档 | ❌ **必须改**（当前就是这个状态） |

⚠️ 修饱和时**直接做成分探测器可配**，别只调全局增益——否则要返工两次。将来加到 5 cm 时差 **50.6 dB（11 万倍）**，更不可能共档。

## T0.4 波长扫描顺序

**在问什么**：五个波长轮流点亮，前一个的余量有没有拖到后一个？（建立时间够不够）

**怎么做**：正序 / 逆序 / 随机各扫一遍，比较各波长读数。

**看什么**

| 结果 | 结论 |
|---|---|
| 三种顺序读数一致 | ✅ 建立充分 |
| 有差异 | ⚠️ 建立时间不足 |

参考：2% 的残留会造成约 **2.8%** 的正逆序读数差。

⚠️ 这一项**对 MBLL 容差很宽**（5% 残留只造成 0.8% 的 HbO 误差，因为在 ΔA 里大部分抵消），**但走 SRS 就重要**——SRS 用绝对斜率，没有抵消机制。**零成本，顺手做掉。**

---

# 阶段 1：体模 + 功率计

**体模**：指定 μa ≈ 0.15 cm⁻¹、μs′ ≈ 10 cm⁻¹ 那块（Φ100 × 50 mm，n = 1.42）

**功率计**：⭐ **必须有校准证书且在有效期内**。仪器编号与证书号要记进试验记录（送检也要用同一台）。

**定位工装**：功率计探头和设备探头要能**换到同一位置**，且压力一致。这是本阶段的主要误差来源。

⚠️ 索取体模的**完整测试报告**（685/808/830/980 四波长的 μa、μs′ 及标准差）。

## T1.1 绝对响应度 ⭐ 本阶段核心

**在问什么**：设备读出的一个 ADC 计数，对应多少瓦的光？

**为什么这一步最有价值**：它把你的读数接到了**可溯源的物理单位**上。**不需要体模的任何参数，也不需要任何模型**——体模在这里只是提供一个稳定、漫射、可重复的光场。

**怎么做**

```
① 功率计压在体模上（探测器位置）→ 记 P_det(λ)   [瓦]
② 换成设备探头，压在同一位置     → 记 C(λ)      [ADC 计数]
③ 绝对响应度 = C(λ) / P_det(λ)                  [计数/瓦]
```

**每换一个波长，功率计上的波长设定也要跟着改。** 硅探测器的响应度在 700~850 nm 差 20~30%，设错了读数直接错。

**看什么**

| 项 | 判据 |
|---|---|
| 各波长的 counts/W | 重复 4 次应稳定 |
| 与预期量级 | 差 10 倍以上 → 有污染／装配错误／错件 |

**功率计够不够得到**（LED 注入 5 mW、收光面积 3×3 mm、本底 ~1 nW）

| ρ | 收到功率 | 能测吗 |
|---|---|---|
| 1 cm | 5.26 µW | ✅ |
| **3 cm** | **9.2 nW** | ✅ |
| 4 cm | 612 pW | ⚠️ 勉强 |
| 5 cm | 46 pW | ❌ |

⇒ **现有 1cm + 3cm 配置完全可行。** 将来 SRS 的 4/5 cm 够不到，要另想办法。

## T1.2 五波长响应一致性

**在问什么**：五个波长之间，设备的响应差多少？差得均不均匀？

**怎么做**：直接用 T1.1 的结果，看 `C(λ)/P_det(λ)` 这一列随波长怎么变。

**为什么这样就够**：功率计和设备探头的几何差异（面积、接受角）是个**常数**，不随波长变，所以除下来剩的就是设备自己的波长响应。

**看什么**

- 对 **MBLL / 现在的送检**：⚠️ **这一项不重要**。MBLL 算的是同一探测器同一波长两个时刻的比值，增益直接约掉（实测偏差 1.4×10⁻¹⁴）。
- 对 **SRS**：⭐ 关键。要求两个探测器的**响应度比值**在五个波长上基本恒定，波动 **<1%**。

⚠️ 1% 对应 **0.043 dB**，很小。**需 ≥4 次平均才能分辨 1%，≥16 次分辨 0.5%。**

## T1.3 光强水平核对

**在问什么**：读数量级对不对？动态范围配置合理吗？

**怎么做**：1 cm 探测器增益调到读数约 **80% 满量程**，逐波长记两个探测器读数（扣除 `D`）。

**看什么**（按满量程 6.6 M、μa=0.15/μs′=10 估算）

| 探测器 | 预期读数 |
|---|---|
| S1_D2 (1 cm) | 5 280 000（80%） |
| S1_D1 (3 cm) | **9 261**（0.14%） |
| 比值 | 570 倍 = **27.6 dB** |

⚠️ 上表按**假定**光学参数算。**收到报告后必须用实际认证值重算**——同样是 1cm/3cm，跨整个矩阵从 15.6 到 49.6 dB 都有。

**判据**：3 cm 读数 **> 2000 计数**，否则有效位不够，达不到 0.5% 稳定性目标。

## T1.4 增益时间稳定性 ⭐ 送检前提

**在问什么**：连续测几小时，读数会不会慢慢漂？

**为什么重要**：这是守住附录 BB **<5%** 判据的隐含前提。

**怎么做**：探头固定不动，连续采 **≥4 小时**，同步记温度。

**看什么**

| 漂移 | HbO 偏差 |
|---|---|
| 0.1% | 0.4% |
| **0.5%** | **2.3%** ✅ |
| 1.0% | 4.3% ⚠️ |
| 2.0% | 8.8% ❌ |

**判据：整个测量时长内漂移 < 0.5%**

**要一起看**：预热多久才稳、漂移和温度相不相关、是单调漂还是随机游走。

## T1.5 耦合重复性

**在问什么**：取下来再贴上去，读数能重复到什么程度？

**怎么做**：贴合 → 记录 → 取下 → 重贴，**≥16 次**，每次采 30 秒取均值。

**看什么**

| 耦合变化 | ΔHbO 偏差 |
|---|---|
| 0.5% | 1.4% |
| 1% | 2.9% |
| **2%** | **5.8%** ⚠️ |

**判据：16 次的标准差 ≤ 1~2%**

## T1.6 双通道一致性与噪声本底

**怎么做**：ch1 / ch2 先后测同一块同一位置；另在稳定贴合状态下连采 10 分钟。

**看什么**
- 两通道读数比值应**稳定可重复**。差异本身不是问题（可标定），**不稳定**才是问题
- 逐波长逐探测器的标准差 → 有效位 → 确认 16 次平均后能分辨 0.5%

---

# 阶段 2（可选）

## T2.1 小信号线性度

**在问什么**：在**接近真实脑激活的量级**上，ΔA 测得准吗？

**为什么单独做**：换块或换体模产生的信号是真实脑激活的 **145 倍**，验不到小信号区。

**怎么做**：探头贴稳 → 记 `I_A` → 插入已知 X dB 的中性密度滤片 → 记 `I_B` → 算 `log₁₀(I_A/I_B)`，与 `X/10` 比。

**判据**：误差 **< 5%**

**好处**：波长无关的已知衰减，**不需要体模认证值**，滤片可独立溯源，比体模便宜。

⚠️ 插片会改变光路耦合，需固定夹具；滤片本身的波长平坦度要确认。

## T2.2 增益档切换点

**在问什么**：增益换档的那一刻，读数连不连续？

**为什么**：档位切换点是最容易出问题的地方——跳变、迟滞、标称倍数不准。单一光强水平验不到。

**怎么做**：用 ND 滤片让读数缓慢扫过一个切换点，看有无跳变。

---

# 结果记录表

| 项 | 判据 | 实测 | 结论 | 日期 |
|---|---|---|---|---|
| T0.1 暗电平 | < 1% 满量程 | | | |
| **T0.2 光学串扰** | **< 2% 于最暗通道** | | | |
| T0.3 独立增益档 | 支持 | | | |
| T0.4 扫描顺序 | 三种顺序一致 | | | |
| **T1.1 绝对响应度** | **4 次重复稳定** | | | |
| T1.2 波长响应一致性 | SRS 需 <1%；MBLL 不适用 | | | |
| T1.3 光强水平 | 3 cm > 2000 计数 | | | |
| **T1.4 时间稳定性** | **< 0.5% / 4 h** | | | |
| T1.5 耦合重复性 | ≤ 1~2% | | | |
| T1.6 双通道 / 噪声 | 比值稳定 | | | |
| T2.1 小信号线性度 | < 5% | | | |
| T2.2 档位切换 | 无跳变 | | | |

---

# 不在本流程内的

| 要验什么 | 需要什么 | 去哪看 |
|---|---|---|
| **ΔHbO/ΔHbR 数值准确度** | **变孔径体模** + 校准功率计 | `检验方法.md` §4 |
| 斜率线性度 | ≥3 个长距探测器 | `SRS路线.md` §6 |
| 增益标定 | **3×4 二维体模矩阵**（单块不可分离） | `SRS路线.md` §4.2 |
| SSR 临床增益 | **分层体模** | `软件验证报告.md` 缺口表 |
| 电磁兼容 | 独立送检项 | — |

---

# 备注

- 判据中的 HbO / ΔA 偏差数值来自 `fnirs_pipeline` 实测仿真与 `tools/srs_reference.py` 正向模型，适用边界为均匀半无限介质 + Farrell-Patterson 稳态扩散解。
- T1.3 的预期读数按**假定**光学参数计算，**收到认证报告后必须重算**。
- **阶段 0 四项即使 SRS 不立项也必须完成**——它们是 MBLL 送检的前提。

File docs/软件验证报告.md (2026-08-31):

# 离线处理链路 —— 软件验证报告

> 验证对象：`fnirs_pipeline` 的离线反演链路
> 验证手段：公开 fNIRS 数据集 + 独立实现交叉核对
> 用途：YY/T 0664—2020（= IEC 62304 MOD）软件验证证据
>
> ⚠️ **本报告不涉及绝对准确度**。Δc·L 的准确度由 GB 9706.271 附录 BB 的体模试验承担，见 `检验方法.md`。

---

## 0. 摘要

| 项 | 结果 |
|---|---|
| **端到端与公开数据集发布结果的一致性** | **r 中位 0.99867**，7 组被试 630 通道，99.2% 通道 r>0.99 |
| **幅度偏差** | **k = 1.016 ± 0.023**（+1.6%） |
| **发现并修复的缺陷** | `smart_bandpass` 的 `padlen` 严重不足（15 vs 应有 300） |
| **修复效果** | 25 组 × 6 工况 × 27000 次比对，全部达到 r = 1.00000 |
| **SSR 实现正确性** | 1216 组回归：正交性 1.09e−17、β 随输入质量单调、阴性对照 β→0 |
| **未覆盖** | 绝对准确度、SSR 临床增益、生产入口编排、协议解析 |

---

## 1. 验证范围

### 1.1 覆盖的链路

```
原始光强  →  intensities_to_od_changes  →  ΔOD
             ↓
          short_separation_regression（SSR）
             ↓
          smart_bandpass（带通 0.01–0.1 Hz，4 阶）
             ↓
          ε 表插值 + 两色团最小二乘  →  ΔHbO / ΔHbR
```

### 1.2 不在范围内

| 项 | 原因 | 由谁承担 |
|---|---|---|
| Δc·L 绝对准确度 | 公开数据集无物理溯源 | `检验方法.md` 附录 BB 体模试验 |
| Cyt 第三色团 | 数据集波长不在 Cyt 表内 | 见 §5 |
| 在线因果路径 | `causal_processor` 用 `sosfilt`+`zi`，与离线是两套实现 | 待补 |
| 协议解析、采集 | 使用第三方数据 | 待补 |

> **Cyt 不影响 HbO/HbR**：`generalized_mbll` 中 `hb_delta_c = pinv(a_hb) @ delta_od` 先行求解且不回写，Cyt 仅从残差估计。实测两色团解与三色团解的 HbO/HbR 完全相同（`[+231.28, +146.61]` vs `[+231.28, +146.61]`）。

---

## 2. 数据来源

### 2.1 数据集 A：HEFMI-ICH（端到端比对）

| 项 | 内容 |
|---|---|
| 出处 | *Scientific Data* **12**:1816 (2025)，DOI `10.1038/s41597-025-06100-7` |
| 仓库 | figshare `10.6084/m9.figshare.28955456`（494 文件 / 13.17 GB） |
| 设备 | NirScan（丹阳慧创），连续波 |
| 波长 | **730 / 808 / 850 nm** |
| 采样率 | **11 Hz**，时长约 900~1000 s |
| 几何 | 32 源 + 30 探测器 → **90 通道，全部 3.0 cm** |
| 原始数据 | `.nirs`（Homer2 格式，含原始光强 `d`） |
| 处理后数据 | `_epo.mat`（HbO/HbR/HbT，已分段） |
| 本次使用 | **25 个 `.nirs`** + **10 个 `_epo.mat`** + `code.zip` |

**该数据集处理配方**（取自 `code.zip` 内明文的 `EpoDataMaking/HC_Calculate.m`）：

```matlab
hpf=0.01;  lpf=0.1;        % 带通
ppf=[6 6 6];               % DPF
od = HC_Intensity2OD(d);
od = HC_BandpassFilt(od, fs, hpf, lpf);
dc = HC_OD2Conc(od, SD, ppf);
```

⚠️ 其带通截止频率与本项目 `config.py` 的 `BP_LOW_HZ=0.01` / `BP_HIGH_HZ=0.1` **完全一致**，属独立佐证。

### 2.2 数据集 B：luhmann20synhrf（SSR 验证）

| 项 | 内容 |
|---|---|
| 出处 | *Frontiers in Neuroscience* (2020)，DOI `10.3389/fnins.2020.579353` |
| 仓库 | NITRC `luhmann20synhrf`，BSD 许可，`resting_state_1.zip`（474 MB） |
| 作者 | von Lühmann, Li, Gilmore, **Boas, Yücel**（Boston University Neurophotonics） |
| 设备 | TechEn CW6 |
| 波长 | **690 / 830 nm** |
| 采样率 | **50 Hz**，时长 302 s |
| 几何 | **短距 8 mm × 8 通道 + 长距 30 mm × 26 通道** |
| 关键特性 | **合成 HRF 只注入长距**，短距为纯生理噪声；另有 4 个长距未注入，构成内置阴性对照 |
| 本次使用 | 全部 **14 被试**（`resting_hrf_100.snirf`） |

---

## 3. 方法

### 3.1 三种参照

| 参照 | 定义 | 用于 |
|---|---|---|
| **独立实现** | 不调用项目任何代码的 numpy 复现 | 逐函数比对（L1/L2） |
| **理论基准** | 同一滤波器、`padlen = n−1`（边界处理上限） | padlen 修复验证 |
| **发布结果** | 数据集 A 的 `_epo.mat` | 端到端比对 |

### 3.2 被试配对

`_epo.mat` 的文件名不含被试信息（全是 `1/2/3_epo.mat`），采用**互相关自动配对**：

- 指纹 = `epo.oxy.EO`，即 marker 31 起的 60 s 睁眼静息段（661 × 90）
- 用本项目管线从每个 `.nirs` 算出同一段，逐通道求相关

**区分度充分**：同一被试 r > 0.99，其余 24 个候选全部 |r| < 0.4。

### 3.3 指标

$$r=\frac{(a-\bar a)\cdot(b-\bar b)}{n\,\sigma_a\,\sigma_b},\qquad k=\frac{(a-\bar a)\cdot(b-\bar b)}{(b-\bar b)\cdot(b-\bar b)}$$

`r` 反映波形一致性（与幅度无关），`k` 是最佳拟合比例（`本项目 ≈ k × 参照`）。

**k 的诊断价值**：

| k | 含义 |
|---|---|
| 2.303 | log10 与自然对数混用 |
| 0.434 | 反向 |
| ≈1 | 仅余 ε 表等细微差异 |

---

## 4. 验证结果

### 4.1 发现并修复的缺陷：`padlen` 严重不足

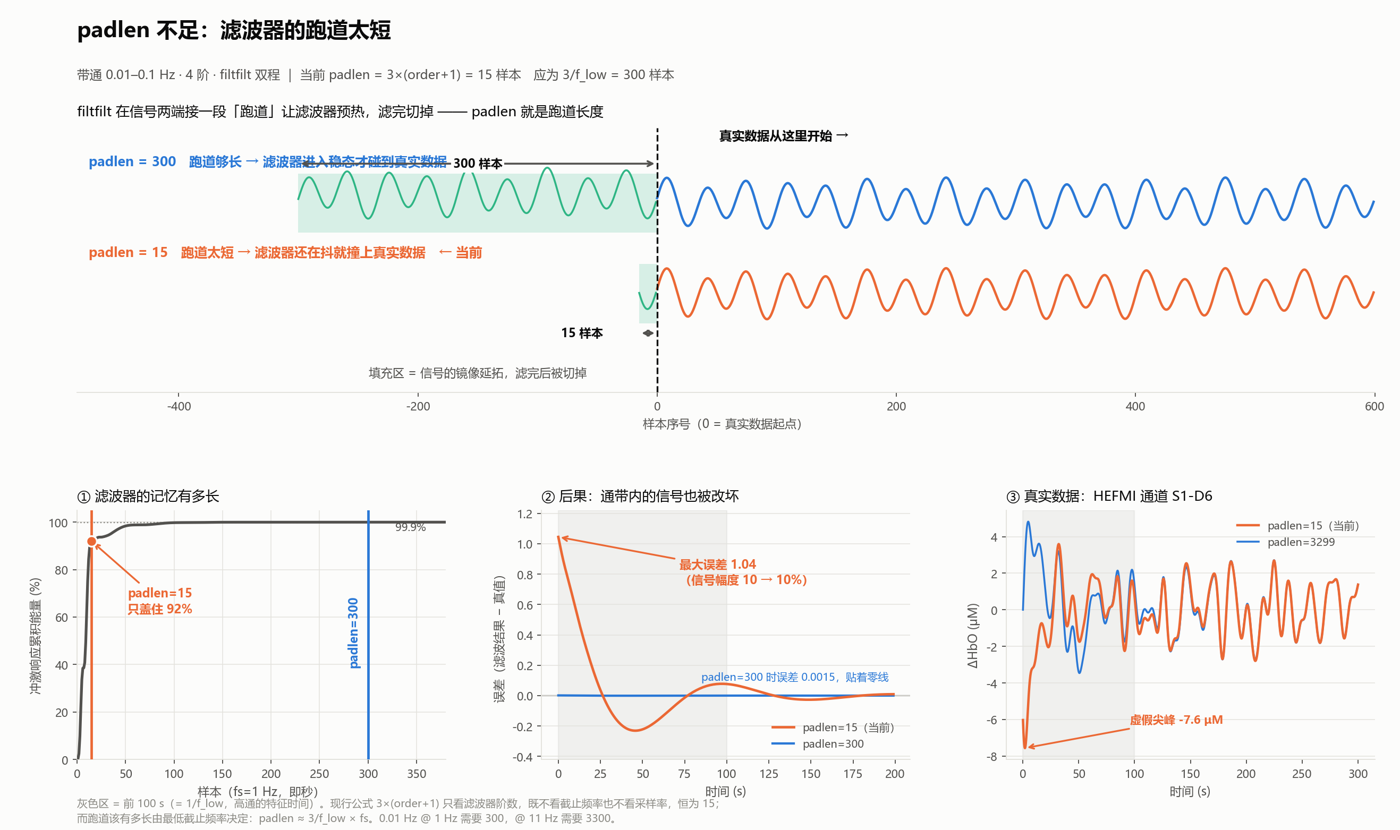
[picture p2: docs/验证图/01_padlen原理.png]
padlen 原理


**问题**：`smart_bandpass` 中

```python
padlen = min(data_ds.shape[1] - 1, 3 * (order + 1))   # 恒为 15
```

该公式只看滤波器阶数，**不看截止频率也不看采样率**。而 `filtfilt` 的边界填充长度应由最低截止频率决定：0.01 Hz 高通的特征时间约 100 s，@1 Hz 需 **300 样本**，@11 Hz 需 **3300 样本**——**短了 20~220 倍**。

**实测后果**：

| 场景 | 表现 |
|---|---|
| 纯通带内正弦（幅度 10） | 开头误差 **1.04**（10%），拖 100 s 才收敛 |
| HEFMI 通道 S1-D6 | 开头出现 **−7.6 μM 虚假尖峰** |
| 全体通道前 20 s 幅度 | **系统性偏小 6.7%**（伪影压制了真实信号） |

**修复**（[`fnirs_pipeline/mbll.py:64`](fnirs_pipeline/mbll.py)）：

```python
want = 3 * (order + 1)
if lowcut > 0:
    want = max(want, int(round(3.0 * fs_ds / lowcut)))
padlen = min(data_ds.shape[1] - 1, want)
```

三个要点：保留原值作下限；用**降采样后**的 `fs_ds`；受 `n−1` 封顶。

**修复验证**：

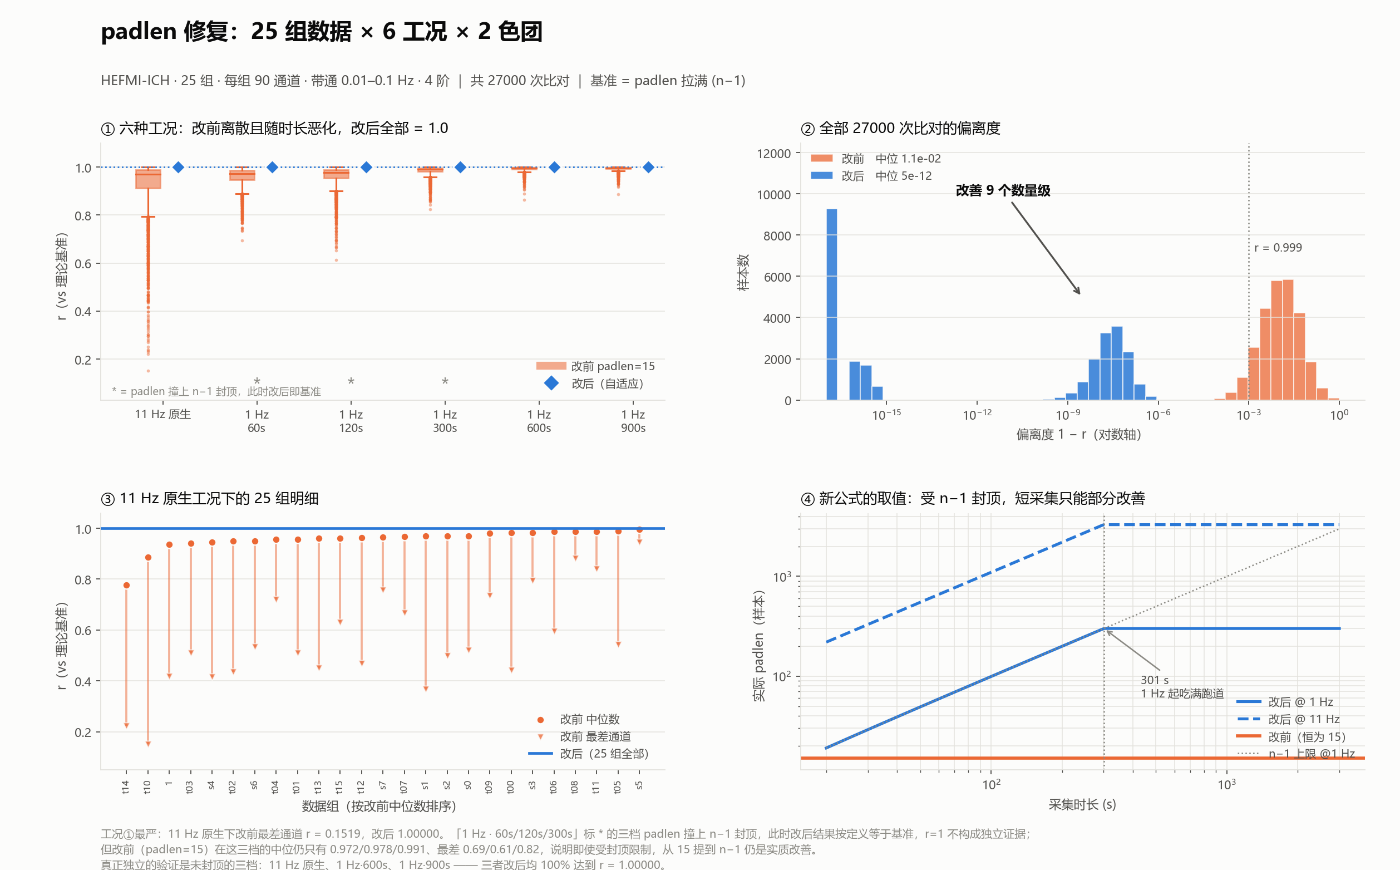
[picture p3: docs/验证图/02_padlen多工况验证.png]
padlen 多工况


25 组数据 × 6 工况 × 90 通道 × 2 色团 = **27000 次比对**：

| 工况 | padlen | 改前中位 | 改前最差 | 改后 |
|---|---|---|---|---|
| **11 Hz 原生** | 3300 | 0.96934 | **0.1519** | **1.00000 · 100%** |
| 1 Hz · 60 s ✱ | 59 | 0.97245 | 0.6949 | 1.00000 · 100% |
| 1 Hz · 120 s ✱ | 119 | 0.97789 | 0.6139 | 1.00000 · 100% |
| 1 Hz · 300 s ✱ | 299 | 0.99122 | 0.8233 | 1.00000 · 100% |
| **1 Hz · 600 s** | 300 | 0.99571 | 0.8629 | **1.00000 · 100%** |
| **1 Hz · 900 s** | 300 | 0.99660 | 0.8868 | **1.00000 · 100%** |

✱ 标记的三档 `padlen` 撞上 `n−1` 封顶，此时改后结果按定义等于基准，r=1 不构成独立证据。**独立验证由未封顶的三档承担**（11 Hz 原生、1 Hz·600s、1 Hz·900s）。

⚠️ **边界**：@1 Hz 需采集 **≥301 s** 才吃满跑道；更短时退回 `n−1`，只能部分改善。这是滤波器的物理性质，非代码缺陷。

**性能影响**：耗时 +5%~13%，绝对增量 **0.02~0.03 ms**，可忽略。
**在线路径不受影响**：`causal_processor` 用 `sosfilt` + 持久 `zi`，不存在 `padlen`。

### 4.2 端到端比对

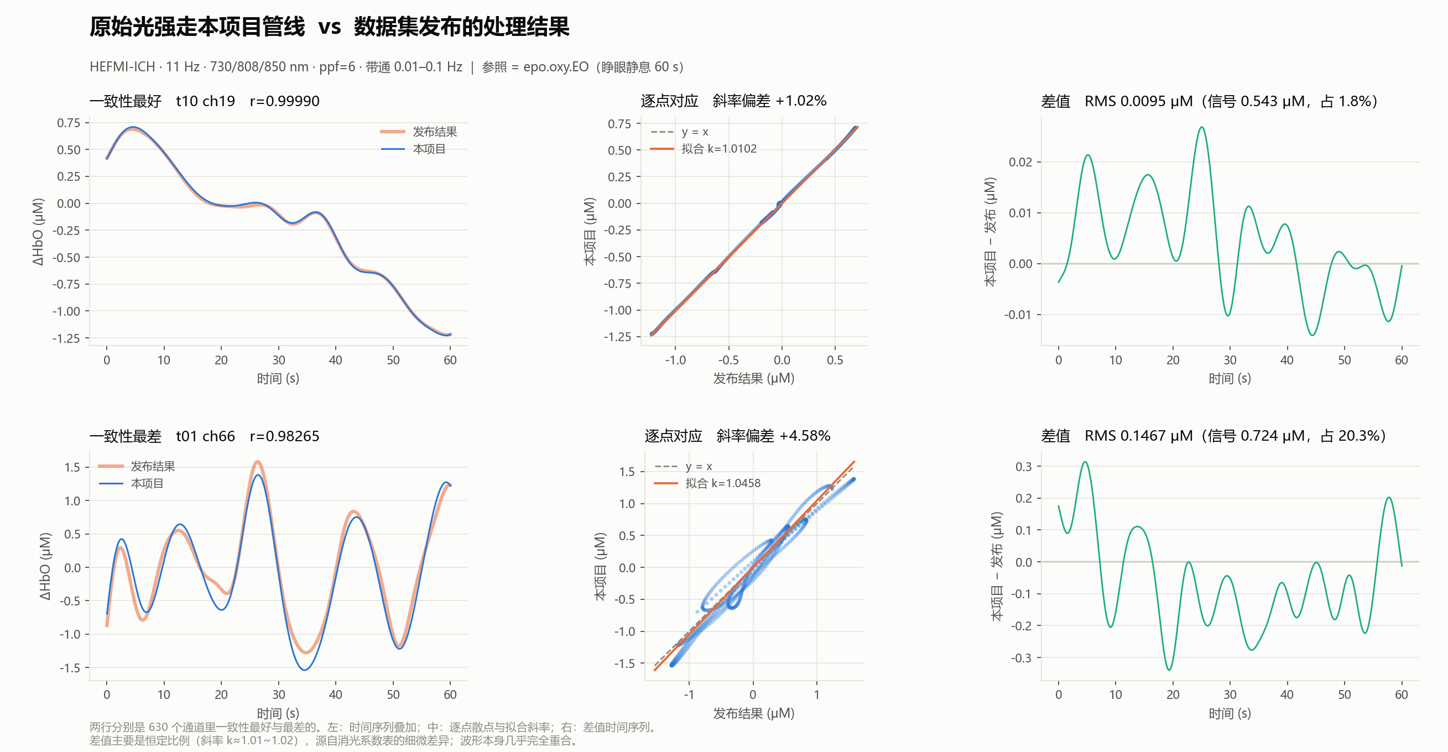
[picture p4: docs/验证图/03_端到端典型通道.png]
典型通道


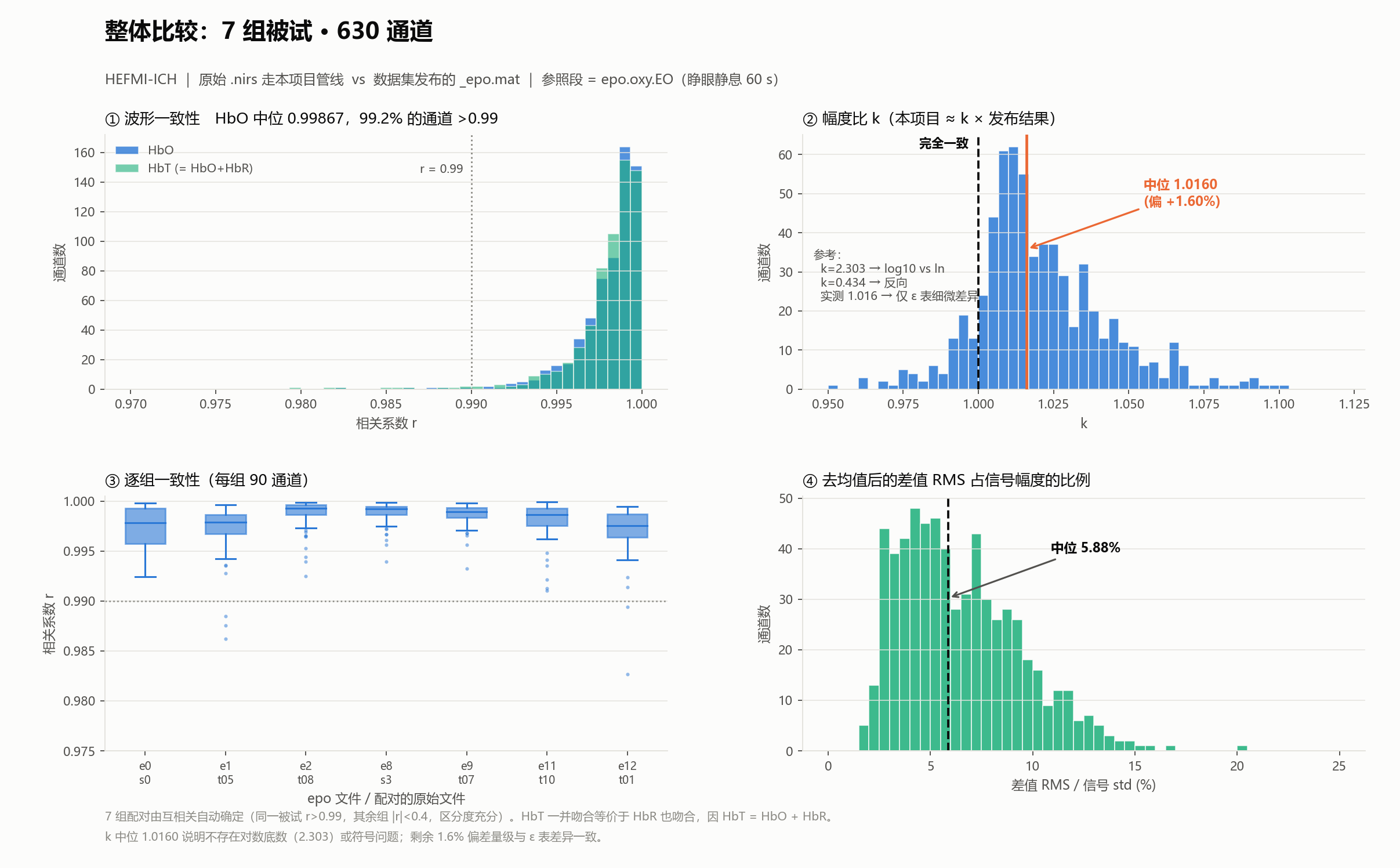
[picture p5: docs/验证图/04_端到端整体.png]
整体


**7 组被试 / 630 通道**：

| 指标 | 值 |
|---|---|
| **HbO r 中位** | **0.99867** |
| 最差通道 | 0.9826 |
| **r > 0.99 占比** | **99.2%** |
| **幅度比 k 中位** | **1.0160 ± 0.0228** |
| 差值 RMS / 信号 中位 | 5.88% |
| HbT r 中位 | 0.99861 |

**逐组明细**：

| epo | 原始 | r 中位 | 最差 | k 中位 |
|---|---|---|---|---|
| e0 | s0 | 0.99783 | 0.9924 | 1.0115 |
| e1 | t05 | 0.99792 | 0.9862 | 1.0126 |
| e2 | t08 | 0.99931 | 0.9925 | 1.0240 |
| e8 | s3 | 0.99920 | 0.9939 | 1.0120 |
| e9 | t07 | 0.99896 | 0.9933 | 1.0114 |
| e11 | t10 | 0.99865 | 0.9910 | 1.0147 |
| e12 | t01 | 0.99755 | 0.9826 | 1.0365 |

**关键结论**：

- **k = 1.016，排除对数底数问题**（2.303）与符号问题（0.434）
- 剩余 1.6% 偏差量级与 ε 表差异一致
- **睁眼（EO）与闭眼（EC）两个独立时段各自吻合**（r 0.99783 / 0.99621），非单段巧合
- **HbT 一并吻合等价于 HbR 也吻合**，因 HbT = HbO + HbR

### 4.3 消光系数表对照

本项目使用 `tables/wray.csv`（Wray et al.，650~1042 nm，3 nm 步长）。与两套公开参照的差异：

| λ (nm) | HbO wray | HbO Prahl | 差 | HbR wray | HbR Prahl | 差 |
|---|---|---|---|---|---|---|
| 850 | 1097.0 | 1058.0 | +3.7% | 781.0 | 691.3 | +13.0% |
| 810 | 914.3 | 864.0 | +5.8% | 798.7 | 717.1 | +11.4% |
| 770 | 701.0 | 650.0 | +7.8% | 1425.0 | 1311.9 | +8.6% |
| **730** | 510.0 | 390.0 | **+30.8%** | 1296.5 | 1102.2 | +17.6% |
| **700** | 419.3 | 290.0 | **+44.6%** | 1827.7 | 1794.3 | +1.9% |

对最终 Δc 的影响：ΔHbO 差 3~6%，ΔHbR 差 11~16%（五波长最小二乘稀释了短波端的大偏差）。

与 GB 9706.271 附录 BB.3.1 算例引用的 Matcher 值相比，用 `wray.csv` 复算标准算例偏 **+9.6% (HbO) / −12.5% (HbR)**。

> ⚠️ **对送检的影响**：该偏差超过附录 BB 的 5% 判据。**方案中必须规定参考侧与设备侧使用同一张 ε 表**（见 `检验方法.md` 附 D 第 7 条），并在说明书中披露所用表的来源与取值。

### 4.4 SSR 短距回归链路

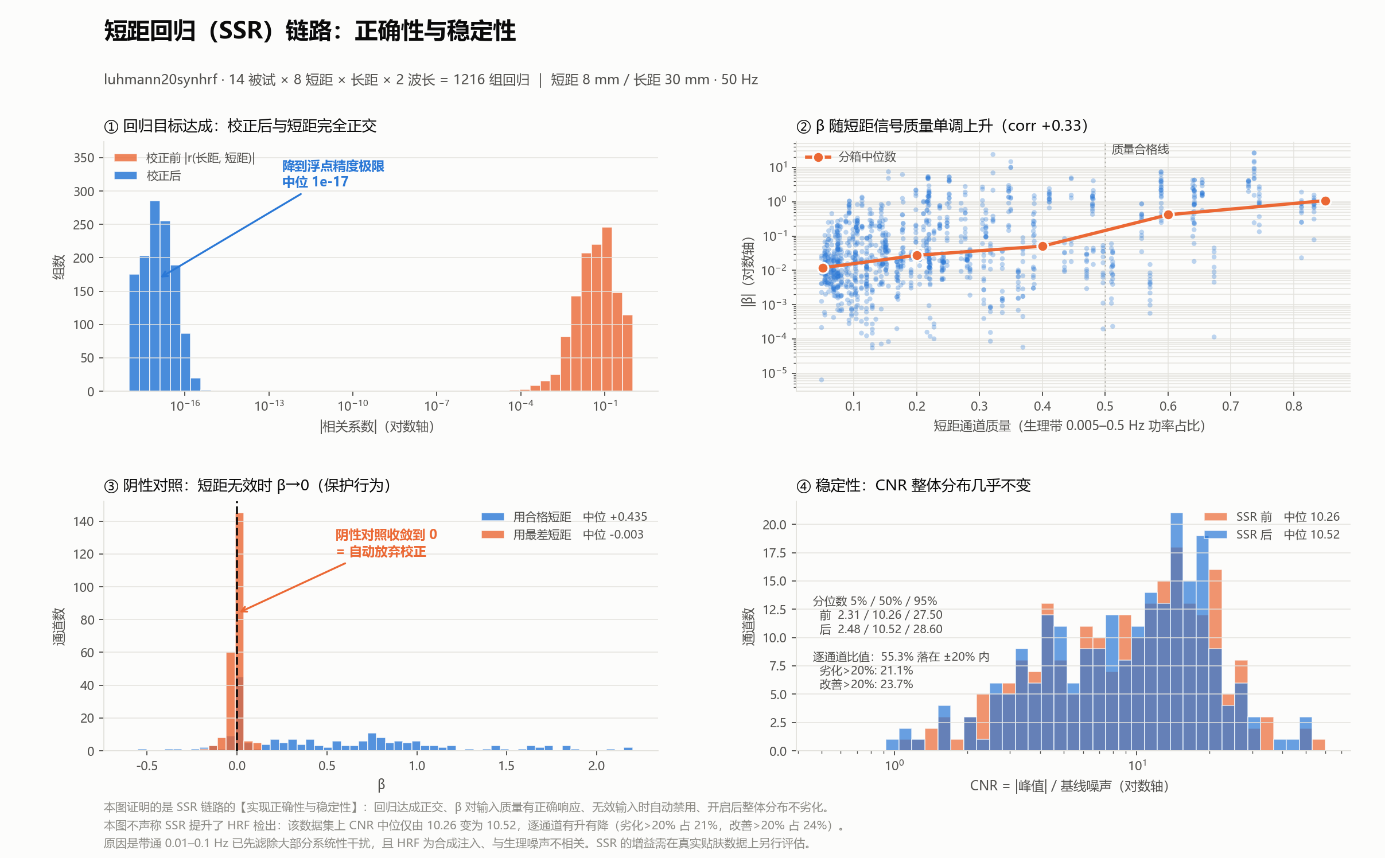
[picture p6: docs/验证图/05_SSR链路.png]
SSR


**1216 组回归**（14 被试 × 8 短距 × 长距 × 2 波长）：

**① 回归目标达成**

校正后长距与短距的相关：**0.0545 → 1.09e−17**（浮点精度极限），最小二乘正交性完全达成。

**② β 随输入质量单调响应**

| 短距质量（生理带 0.005–0.5 Hz 功率占比） | n | \|β\| 中位 |
|---|---|---|
| 0.0–0.1 | 300 | 0.0119 |
| 0.1–0.3 | 536 | 0.0275 |
| 0.3–0.5 | 204 | 0.0506 |
| 0.5–0.7 | 120 | 0.4167 |
| **0.7–1.0** | 56 | **1.0755** |

跨度 **90 倍**，corr(质量, \|β\|) = **+0.33**。

**③ 阴性对照（保护行为）**

用最差短距时 β 中位 **−0.003**，用合格短距时 **+0.435**。**短距无效时自动禁用校正**。

> 这解释了此前观察到的 `S1_D1` 饱和时 β≈0 现象——不是缺陷，是保护机制生效。

**④ 稳定性**

CNR 分位数 5%/50%/95%：**2.31/10.26/27.50 → 2.48/10.52/28.60**，整体分布几乎不变。

⚠️ 逐通道有波动：55.3% 落在 ±20% 内，**21.1% 劣化 >20%，23.7% 改善 >20%**。

**⚠️ 未能证明的**：SSR 提升 HRF 检出。该数据集上 CNR 中位仅由 10.26 变为 10.52。原因有二：

1. 带通 0.01–0.1 Hz 已先滤除大部分系统性生理干扰（Mayer 波 ~0.1 Hz、呼吸 ~0.25 Hz、心跳 ~1 Hz 均在通带外）
2. 该数据集的 HRF 为合成注入，与真实生理噪声不相关

**SSR 的临床增益需在真实贴肤数据或分层体模上另行评估。**

> 附带发现：该数据集 8 个短距通道中仅 2 个信号质量合格（>1.5 Hz 噪声占比 <10%），其余 6 个噪声主导（67~80% 功率在 >1.5 Hz）；短距光强中位反而比长距低 10 倍。**按几何最近配对会选中坏通道，必须先做质量筛选。**

---

## 5. 覆盖清单

### 5.1 已验证

| 生产函数 / 环节 | 证据 | 数据量 |
|---|---|---|
| `intensities_to_od_changes` | 与独立实现差 **0.000e+00** | 810 通道 |
| `butter_bandpass_sos` | 同上 | 27000 次 |
| `smart_bandpass`（含新 padlen） | **r = 1.00000** vs 理论基准 | 27000 次 |
| `hemoglobin_extinctions`（插值） | 端到端 | 630 通道 |
| **两色团最小二乘反演** | **r 中位 0.99867** vs 发布结果 | 630 通道 |
| `short_separation_regression` | 正交性 + β 响应 + 阴性对照 | 1216 组 |
| 对数底数约定 | k = 1.016，排除 2.303 | 630 通道 |
| 数值条件 | cond(E) = 3.58；五波长优于三波长 | — |

### 5.2 未验证

| 项 | 原因 | 补法 | 成本 |
|---|---|---|---|
| **绝对准确度** | 公开数据集无物理溯源 | 附录 BB 体模试验 | 送检时做 |
| **SSR 临床增益** | 数据集条件不适合 | 真实贴肤数据 / 分层体模 | 中 |
| `compute_all_channel_concentrations` | 验证时刻意绕开 | 用自有历史数据端到端自测 | **低** |
| `prepare_interleaved_dataframe` | 数据格式不同 | 合成 `all_groups.csv` 往返测试 | **低** |
| 波长相关 DPF 广播 | 数据集用标量 ppf=6 | 自有数据；合成已验（3.4e−16） | 低 |
| 五波长解混 | 数据集仅三波长 | 自有设备数据；合成已验 | 中 |
| Cyt 分步法与串扰 | 808 nm 不在 Cyt 表内 | 见 §6 | 低 |
| 在线因果路径 | 与离线是两套实现 | 单独设计 | 中 |
| 协议解析、采集 | 使用第三方数据 | 单独设计 | 中 |

---

## 6. 附带发现（待处理）

### 6.1 `_cyt_extinction_vector` 硬编码字典

[`fnirs_pipeline/mbll.py:99`](fnirs_pipeline/mbll.py)：

```python
return np.asarray([CYT_DIFFERENCE_EXTINCTION[float(wl)] for wl in wavelengths]) * 1000.0
```

`CYT_DIFFERENCE_EXTINCTION` 仅含 `{700, 730, 770, 810, 850}`，**任何其他波长直接 KeyError**（如 808 nm）。而同一函数内的 `hemoglobin_extinctions` 是 `np.interp` 插值，**两者容忍度不一致**。

对本项目自有五波长无影响，但阻断了用外部数据集验证 `generalized_mbll` 完整路径。**建议改为插值以保持一致。**

### 6.2 数据集 A 自身的缺陷（供引用时注意）

`MakeDatasetFromRaw.m:154`：

```matlab
% doxy
nirs_data = Hbt;    % ← 应为 Hbr
```

导致 `epo.doxy` 与 `epo.toxy` 内容完全相同（均为 HbT）。已实测证实（最大差 0.000e+00）。**引用该数据集时不可使用 `epo.doxy` 作为 HbR。**

---

## 7. 结论

**光强 → ΔOD → 带通 → 两色团 MBLL 这一段离线反演链路，已通过真实设备数据验证**：与国际公开数据集的发布结果在 7 组被试、630 通道上吻合，相关系数中位 **0.9987**，幅度偏差 **1.6%**。

**验证过程中发现并修复了一处实质缺陷**（`padlen` 不足），修复效果经 25 组数据、6 种工况、27000 次比对确认。

**SSR 链路的实现正确性与稳定性已验证**（1216 组回归），临床增益待评估。

**待补的三项中，两项成本很低**（生产入口自测、配对重排往返测试），建议在送检前完成。

**绝对准确度不在本报告范围**，由 `检验方法.md` 的附录 BB 体模试验承担。

---

## 附 A：复现步骤

```bash
# 1. 数据集 A（figshare，无需登录）
#    元数据: https://api.figshare.com/v2/articles/28955456
#    下载 .nirs 与 _epo.mat（文件 id 见元数据）

# 2. 数据集 B（NITRC，需注册登录）
#    https://www.nitrc.org/projects/luhmann20synhrf/  ->  resting_state_1.zip

# 3. 数据集配置探查
python tools/verify_dataset.py --info path/to/subject.nirs

# 4. 自检（合成数据，不需数据集）
python tools/verify_dataset.py --selftest

# 5. L1/L2 逐函数比对
python tools/verify_dataset.py --compare path/to/subject.nirs

# 6. 端到端配对与比对
python tools/match_epo.py e0.mat
python tools/compare_all.py

# 7. SSR 验证
python tools/ssr_v2.py
```

## 附 B：脚本清单

| 脚本 | 用途 |
|---|---|
| `tools/verify_dataset.py` | 读 `.nirs`/`.snirf`，探查配置，L1/L2 双实现比对，自检 |
| `tools/match_epo.py` | 互相关配对 `_epo.mat` ↔ `.nirs` |
| `tools/compare_all.py` | 多被试端到端比对，输出 r / k 统计 |
| `tools/ssr_validate.py` | SSR 基础设施（读取、分组、事件锁定平均） |
| `tools/ssr_v2.py` | SSR 三路径比较（无 SSR / 合格短距 / 最差短距） |
| `tools/verify_bb.py` | 附录 BB 体模试验的离线核验（送检用，见 `检验方法.md`） |

## 附 C：出处

| 内容 | 出处 |
|---|---|
| 数据集 A | [Sci Data 12:1816 (2025)](https://doi.org/10.1038/s41597-025-06100-7) ｜ [figshare](https://doi.org/10.6084/m9.figshare.28955456) |
| 数据集 B | [Front Neurosci (2020)](https://doi.org/10.3389/fnins.2020.579353) ｜ [NITRC](https://www.nitrc.org/projects/luhmann20synhrf/) |
| Prahl 消光系数表 | [omlc.org/spectra/hemoglobin](https://omlc.org/spectra/hemoglobin/summary.html)（Gratzer / Kollias 汇编） |
| Matcher 值 | GB 9706.271—2022 附录 BB.3.1 算例引用 |
| 软件生存周期要求 | YY/T 0664—2020 |

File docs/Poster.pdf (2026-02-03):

## Background & Motivation

## Project Goals

## Key Requirements

Final Design | Method & Results

## Conclusion & Future Work

# A Wearable Functional Near-Infrared Spectroscopy (fNIRS) based Brain Interface

### The Edward S. Rogers Sr. Department of Electrical and Computer Engineering Tony Kim, Bella Huang, Ingrid Wu, Kevin Liu

### Supervisor: Professor Xilin Liu Administrator: Professor Steve Mann

To develop a low-cost, accurate, non-invasive, and ergonomic fNIRS device that prioritizes high mobility and ease of usability, exploring the potentials of fNIRS technology beyond clinical settings.

Functional Near-Infrared Spectroscopy (fNIRS) is a non-invasive neuroimaging method which uses near-infrared light to measure blood oxygen level in the cerebral cortex, based on the modified Beer-Lambert Law (mBLL).

## ΔOD(λ) = ε(λ) ⋅ Δc ⋅ L ⋅ DPF

OD: optical density
ε : extinction coefficient
c: concentration
L: physical pathlength
DFP: differential pathlength factor

The change in optical density (ΔOD) at a given wavelength (λ) reflects how much near-infrared light is absorbed as it passes through brain tissue. Measuring ΔOD allows us to estimate changes in oxy- and deoxyhemoglobin levels, which indicate brain activity.

The fNIRS device integrates custom hardware, firmware, mechanical, and software components into a unified system. Sensors and an electrical control unit with firmware establish the foundation for signal acquisition and data transmission, while software handles analysis and graphical visualization. Finally, the mechanical components consolidate these elements into an ergonomic assembly.

The design includes 25 printed circuit boards based on two distinct cost-optimized layouts. The device supports up to 24 detector channel readings with a sampling frequency of approximately 1kHz, and 8 dual-wavelength emitters (660 nm and 940 nm) to accurately measure changes in oxyand deoxy-hemoglobin concentration levels.

Custom 4-layer PCB design
Analog multiplexing utilizing 8 TMUX1104 inline with 12-bit ADC channels
PCA9685 12-bit 16 channel
PWM controller for emitters 80MHz STM32L476RET6
microcontroller

Custom 2-layer PCB design
Photodiode detection via
transimpedance amplifier,
101 V/V post-AC gain, and
0.0796–159.2 Hz filter.
RMS noise level of ~0.004 V Emitter wavelengths of 660 nm and 940 nm

Parse and filter sensor data Apply ΔOD conversion,
mBLL, and correlation-based signal improvement (CBSI)
Graph raw ADC, ΔHbO, ΔHbR
data and display on GUI
User control for ECU to
customize operation

Conclusion
The team successfully designed and validated a low-cost, ergonomic fNIRS device and a web-based graphical user interface for real-time brain activity monitoring. The final system is able to map direct ADC output, as well as ΔHbO and ΔHbR trends that match theoretical expectations.

Sampling Rate: The device should support a minimum sampling rate of 100Hz.

Future Work
Possible future work may include real-world validation through collaboration with clinical and neuroscience researchers, as well as integrating machine learning techniques for improved noise reduction, cognitive state classification, and trend analysis of fNIRS data.

Real-time Logging: The design should be able to perform accurate real-time data processing and visualization while also keeping record of the data.

Cost: The net material and fabrication cost of the device should be below $1000.

Wearability: The assembled device can be worn, taken apart, and transported during use.

Non-invasiveness: The device should not puncture, burn, irritate the skin, or cause any form of physical harm or strain to the user.

### Project ID: 2024991

Electrical Control Unit | Sensor Modules | Software Processing

Method
Participants completed a task sequence consisting of a 20-second resting period, followed by a 20-second computer-typing task, and concluded with another 20-second resting period while wearing the device. Results
Below are two sample graphs of a single-channel recording targeting the primary motor cortex (M1).
1) Digitalized sensor data representing reflected light intensity 2) Post-processed data of the change in hemoglobin oxygenation levels using mBLL and CBSI. ADC Value

Time (s)

1) Digitalized Sensor Data

Concentration (Molar)

Time (s)

2) Post-Processed Data
Rest | Task | Rest

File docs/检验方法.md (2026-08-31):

# 路径长度依赖的血红蛋白变化量 —— 透射式检验方法

> **依据：GB 9706.271—2022《医用电气设备 第 2-71 部分：功能性近红外光谱(NIRS)设备的基本安全和基本性能专用要求》附录 BB（规范性）**
>
> 本文只涵盖透射式体模试验（101.5 / .6 / .7 / .8）及其前置条件。

---

## 1. 被检性能与测量量

### 1.1 测量量是 Δc·L

本设备基于修正比尔-朗伯定律（MBLL）测量**路径长度依赖的血红蛋白变化量 Δc·L**，**不测量绝对血氧饱和度**。

> **附录 BB.2 原文**：
> 「Δμa 和 L 的值**不能单独从连续光的测量中得到**，而是得到它们的乘积 μa(λi)·L。」
> 「平均光程长 L 目前**很难被测量**。因此，测量的物理量 Δc_O₂Hb·L 和 Δc_HHb·L 是血红蛋白浓度变化和平均光程长的乘积，它们的单位用浓度和距离的乘积表示，如 (mmol/L)·mm。」

平均光程 L 为假设值（DPF 公式与年龄参数须在说明书披露），**不在本方法的验证范围内**。

### 1.2 为什么用透射法

> **BB.3.1 原文**：「采用**透射法**是因为它容易改变光的衰减，**测量精度好**；而反射法通常用于较厚的人体组织。」

附录 BB 为**规范性**附录，101.5 全文即指向它，其试验构型为透射。

### 1.3 本方法能验证什么

| 命题 | 能否 | 说明 |
|---|---|---|
| **Δc·L 幅度是否准确** | ✅ | **判据 <5%**，规范性条文 |
| **HbO/HbR 能否正常升降** | ✅ | A→B 双双上升，B→A 双双下降，方向与量值均可判 |
| 波长间增益一致性 | ✅ | 判据 A2 |
| 响应时间、信号稳定性、信噪比 | ✅ | 101.6 / .7 / .8 |
| **HbO↑ 同时 HbR↓ 的生理反相** | ❌ | 见下 |

⚠️ **体模验不出生理反相，这是标准自己写明的。** 孔径是几何机制，五波长 ΔA 相等，解出必同号：

> **BB.3.1 算例注 1**：「在 690 nm 和 830 nm 衰减增加 3 dB 时，模拟的路径长度依赖的血红蛋白变化量**均为阳性**。」
> **注 3**：「在人体脑激活中发现的典型的衰减变化和相关的路径长度依赖的血红蛋白变化量在**大小和方向上都要小得多**。」

**标准接受这一点**——本试验检的是数值准确度，不是生理仿真。生理反相需人体试验，不在本文范围。

---

## 2. 前置条件

### 2.1 ★ 增益整定与饱和排查

**这是整个方案的第一步，未完成不得进入第 4 节。**

⚠️ 长距通道当前处于**饱和**状态（实测光强 std/mean = **0.00043**），此时所有下游读数无效。

**装置**：稳定的组织类固态体模（μs′ 约 10 cm⁻¹ @800 nm，30 mm 处光损耗约 40 dB），涂折射率匹配介质消除空气间隙。

**步骤**：从最低增益逐档上调，记录各探测器 × 各波长的原始 ADC 值，找到"远离满量程且信噪比足够"的档位，对每个探测器**分别**整定。

| 序号 | 判据 |
|---|---|
| **R1** | 所有探测器、所有波长原始值**远离满量程**（建议 ≤70%），且 std/mean **>0.001** |
| **R2** | 各探测器**支持独立增益档位** |

> ⚠️ **透射式的光强量级与反射式贴肤完全不同**：101.5 要求 >40 dB、101.8 要求 >60 dB 衰减，同一套试验内可能需换档。**"每探测器独立增益且可配置"是必需项。**
>
> ⚠️ 增益变更后，`config.py` 中的贴肤检测阈值（`SKIN_CONTACT_PRESS_MIN` 等）全部作废，须重新标定。

### 2.2 遮光验证

遮挡发射探头出光面，采集 **60 s**。

| 序号 | 判据 |
|---|---|
| **R4** | 输出落至噪声水平，验证无环境光泄漏。**本项是第 3.2 节透射式遮光有效性的前置验证，必须先通过** |

### 2.3 【101.2 / .3 / .4】光源参数

不需要体模，但 **101.3 必须最先做**——后续查 ε(λ) 要用实测峰值波长。

| 条款 | 项目 | 方法 |
|---|---|---|
| 101.2 | 平均光功率 | 发射探头对准**功率计**（图 201.102）；须在 GB 7247.1 皮肤 MPE 限值内 |
| **101.3** | **峰值波长** | 对准**分光光度计/光谱分析仪**（图 201.103），每个光源各测 |
| 101.4 | 光谱功率分布 FWHM | 同上装置 |

**脉冲输出方式下的平均光功率**（公式 1，GB 版新增）：

$$P_{av} = P_{peak}\times\tau\times f$$

> 本设备为五波长时分轮转（脉冲调制），此式适用。

⚠️ **ε 须按实测峰值波长查表**。若实测 848 nm 而按标称 850 查表，整条链路的定量都会偏。

### 2.4 探头组合的选择与记录

**GB 9706.271 201.12.1.101.1 总则**：

> 「在以下性能试验项目中，如果有多个发射探头和接收探头，则应根据每个制造商定义的风险管理，**选择发射探头和接收探头的组合。应记录所选的组合。**」

本设备含两个硬件采集通道（`ACQUISITION_CHANNELS` = ch1 / ch2，与探测器、波长正交），每通道各有独立光源与探测器，据此选择：

| | 使用 |
|---|---|
| **发射探头** | **ch1 的五波长 LED 光源** |
| **接收探头** | **ch2 的长距探测器（S1_D1，3.0 cm）** |

两组探头分列体模两侧，构成透射构型。**器件为同批 LED 与 PD，与量产状态光学等效。**

#### 记录格式（须写入报告）

| 项 | 内容 |
|---|---|
| 发射探头 | ch1，五波长 LED（850/810/770/730/700 nm，峰值按 101.3 实测填写） |
| 接收探头 | ch2，S1_D1（长距 PD） |
| 未使用 | ch1 全部 PD、ch2 光源、ch2 短距 PD |
| 选择依据 | 风险管理文件编号 ______ |
| 等效性说明 | 与量产探头同批器件，NA、有效受光面积、耦合方式一致 |

#### ⚠️ 实施前必须确认

| # | 待确认 | 不满足的后果 |
|---|---|---|
| 1 | 固件中 ch1 与 ch2 的时序是否同步 | 独立时 ch2 的 PD 不在 ch1 的 LED 点亮时刻采样 |
| 2 | **能否只点亮 ch1 光源、只读 ch2 探测器** | 否则 ch2 自身光源会淹没透射信号 |
| 3 | 时间戳精度能否支持跨通道对齐 | PC 侧时间戳为收包时刻，带 TCP 抖动，应依赖设备侧时序 |

**若第 1、3 项不满足**，可用**静态点亮模式**绕过：

```
① ch1 只点亮 850 nm，保持常亮
② ch2 的 PD 持续采样
③ 切换体模状态 A → B，分别记录 I_A、I_B
④ 依次换 810 / 770 / 730 / 700 nm 重复
```

静态点亮下不需要任何跨通道同步。⚠️ **例外**：101.8 要求「ME 设备处于最高采样率时」，该项应在正常轮转模式下进行，否则须在报告中说明。

**若第 2 项也不满足**：改做可分离的送检专用探头（同批器件，仅机械载体可分开）。101.1 总则本身允许并要求记录探头组合，此路径合规。

---

## 3. 试验装置

### 3.1 体模（图 201.BB.1）

```
        入射 I₀ (10)
          ↓
    ┌───────────┐
    │  衰减器6  │  ← 足够厚的散射吸收材料
    ├─────┬─────┤
    │     │孔径9│  ← 可变，面积 S_apA / S_apB (12)
    ├─────┴─────┤
    │  衰减器6  │
    └───────────┘
          ↓
   检测光强 I_A / I_B (11)
```

| 参数 | 要求 | 出处 |
|---|---|---|
| 状态 A 光损耗 | **>40 dB**（信噪比试验时 **>60 dB**） | BB.3.2、表 201.101 |
| 状态 B 光损耗 | 比状态 A **大 3~4 dB**，**在 ME 设备的每个波长上** | BB.3.2 |
| 出口侧圆形孔径 | **2r_ex = 8 mm** | BB.3.2 |
| 材料 | 散射与吸收特性与人体组织相似；孔径**前后**均需足够厚的散射吸收材料 | BB.3.1 |

**光损耗定义**（BB.6）：

$$OL = P_{ex,total}/P_{in},\qquad OL_{dB} = 10\log_{10}(OL)$$

> P_ex,total 为从整个出口孔径区域发射到整个半空间的总功率。
> ⚠️ **BB.3.2 提示**：功率计因传感器面积限制与表面有限距离可能无法采集总功率，**导致对光损耗的高估**，需确定矫正系数。
>
> **单位换算**：X dB 光损耗 = 透过比例 10^(−X/10)。40 dB 即万分之一，60 dB 即百万分之一。**1 OD = 10 dB。**

**孔径面积设计**：按 `S_apB/S_apA = I_B/I_A`，3.5 dB → 面积比 0.447。

> **采购**：可购买符合 IEC 80601-2-71 的商品体模（如 BioPixS fNIRS Phantom，含 ≥60 dB 加装件）。**采购时须问清是否附带各状态的认证光损耗数据/参考值**——若附带可省去自建参考系统。

### 3.2 ⚠️ 遮光

状态 A 衰减 40~60 dB，真实信号只剩万分之一到百万分之一，**任何绕过体模的漏光都会完全淹没有效信号**。

| 部位 | 要求 |
|---|---|
| 探头与体模贴合面 | 完全遮光，黑色遮光垫圈 |
| 体模四周 | 全封闭，防侧向绕射 |
| 整体 | 置于遮光箱内 |
| **验证** | **§2.2 的 R4 必须先通过** |

### 3.3 参考系统（图 BB.2）

```
[稳定光源 13] → [发射探头 2] → [体模 8 (含可变孔径 9)] → [校准功率计 14]
```

> **BB.3.1 原文**：「需要评估产生状态 A 和状态 B 的功能性近红外光谱体模以及能够测量参考光强度变化的参考系统来执行这些程序。**该参考系统由一个稳定的光源和一个校准的功率计组成。**」

#### ⚠️ LED 集成探头的适配

图 BB.2 中稳定光源经光纤注入发射探头。**本设备为 LED 集成探头，外部光注不进去。**

**适配方案：用设备自己的 LED 作源（逐个点亮），校准功率计放在接收探头位置。**

**理由**：BB.2 只用 I_A/I_B 的**比值**，同波长取比值时光源输出与功率计波长响应度均自动约掉；被独立验证的是**探测链**，正是本试验要检的部分。

⚠️ 此适配须写进方案并说明理由。对参考系统的实际要求：

| 要求 | 为什么 |
|---|---|
| 光源在 A、B 两次测量间**稳定** | 漂移直接进入比值 |
| 功率计**线性**、在有效校准期内 | 需跨 nW~mW 多个数量级 |
| 校准证书可溯源 | 送检必需，仪器编号与证书号须写入试验记录 |

---

## 4. 【101.5】路径长度依赖的血红蛋白变化量 ★核心

> **101.5 全文**：「应对路径长度依赖的血红蛋白变化量进行测量并在使用说明书中给出。通过检查使用说明书和**附录 BB 中描述的试验**来检验是否符合要求。」

### 4.1 原理

> **BB.3.1 原文**：「通过改变光学孔径面积来改变透射光强，**相当于改变了整个功能性近红外光谱体模的吸收系数 μa**。孔径面积的比值 (S_apB/S_apA) 表示透射光强的比值 (I_B/I_A)。光的方向性丢失是由于在光学孔径的**前后放置了足够厚的散射和吸收材料**，导致 S_apB/S_apA 等于 I_B/I_A。」

$$\frac{S_{apB}}{S_{apA}} = \frac{I_B}{I_A}$$

**孔径面积比精确等于透射光强比——几何即溯源，不需要体模的任何光学属性（μa、μs′、厚度、折射率均不需要）。**

> 孔径改变的是几何遮挡，**并未改变体模材料的 μa**。但设备只能看到探测光强 I，无法区分"介质吸收变强"与"一部分光被挡住"，二者产生的 ΔA 完全相同。故标准称其"**相当于**改变了吸收系数"——这是**等效**，不是物理改变。
>
> 与真实组织的差别：真实 μa 变化时有效光程 L 也会微变；孔径变化时 **L 完全恒定**。因此本试验是对反演链路更"干净"的检验。

### 4.2 公式（附录 BB 原文）

**BB.1**：

$$\frac{I_B(\lambda_i)}{I_A(\lambda_i)}=\exp\left[-\Delta\mu_a(\lambda_i)\cdot L(\lambda_i)\right]$$

**BB.2 衰减变化定义**：

$$\Delta A(\lambda_i) = \log_{10}\left[\frac{I_A(\lambda_i)}{I_B(\lambda_i)}\right]$$

> 原始定义为 A = log₁₀(I₀/I)，但入射光强 I₀ 无法测量。**取两状态之差后 I₀ 约掉**——这正是 MBLL 能在不知入射光强下工作的原因，也是它只能给变化量的原因。
> ΔA > 0 表示光变暗（吸收增加），设备解读为浓度上升。

**BB.3 MBLL 展开**：

$$\Delta A(\lambda_i) = \varepsilon_{O_2Hb}(\lambda_i)\cdot\Delta c_{O_2Hb}\cdot L + \varepsilon_{HHb}(\lambda_i)\cdot\Delta c_{HHb}\cdot L$$

| 符号 | 含义 | 单位 |
|---|---|---|
| ΔA(λᵢ) | 波长 λᵢ 处的衰减变化 | OD |
| ε | 摩尔（十进）消光系数 | M⁻¹·cm⁻¹ 或 L/(mmol·cm) |
| **Δc·L** | **被测量** | M·cm，或 (mmol/L)·mm |
| L | 平均光程，**假设值，不验证** | cm |

**BB.4 双波长闭式解**：

$$\Delta c_{O_2Hb}\cdot L=\frac{\varepsilon_{HHb}(\lambda_2)\Delta A(\lambda_1)-\varepsilon_{HHb}(\lambda_1)\Delta A(\lambda_2)}{\varepsilon_{O_2Hb}(\lambda_1)\varepsilon_{HHb}(\lambda_2)-\varepsilon_{O_2Hb}(\lambda_2)\varepsilon_{HHb}(\lambda_1)}$$

### 4.3 ⚠️ BB.5 印刷有误 —— 实施时必须更正

**标准原文 BB.5 的分子两项次序颠倒，直接实现会使 Δc_HHb·L 反号。**

用标准自身的算例（BB.3.1，λ₁=690 nm、λ₂=830 nm、ΔA=log₁₀2=0.3010）复核：

| | Δc_O₂Hb·L | Δc_HHb·L |
|---|---|---|
| **标准给出的答案** | 204 μmol/L·cm | **111** μmol/L·cm（注 1：均为阳性） |
| BB.4 复算 | **204.1** ✓ | — |
| **BB.5 按原文实现** | — | **−111.0** ✗ **与标准自己的答案反号** |
| BB.5 按克拉默法则 | — | **+111.0** ✓ |

**正确形式**：

$$\Delta c_{HHb}\cdot L=\frac{\varepsilon_{O_2Hb}(\lambda_1)\Delta A(\lambda_2)-\varepsilon_{O_2Hb}(\lambda_2)\Delta A(\lambda_1)}{\varepsilon_{O_2Hb}(\lambda_1)\varepsilon_{HHb}(\lambda_2)-\varepsilon_{O_2Hb}(\lambda_2)\varepsilon_{HHb}(\lambda_1)}$$

> GB 前言已声明修正过 IEC 的另一处公式错误（101.8 的 δS），**这一处未修正**。
>
> ✅ **规避方法：直接用 `x = pinv(E)·ΔA`，天然正确，无需处理符号。**

### 4.4 五波长求解

$$\Delta \mathbf{A} = \mathbf{E}\cdot\mathbf{x},\qquad \mathbf{x} = \text{pinv}(\mathbf{E})\cdot\Delta\mathbf{A}$$

**E** 为 5×2 消光系数矩阵（**不含光程**——L 已包含在未知数 x = Δc·L 中）。超定，取最小二乘解。

实测 `cond(E) = 3.58`（奇异值 3232.9 / 902.6），条件数小，五波长冗余良好。单波长 +1% 增益误差 → Δc 误差约 **1.06%**，不放大。

> 五个波长在最小二乘中**等权**，某个波长信噪比差会直接污染解——故须做判据 A2 的波长一致性检查。

### 4.5 本项目参考值（850/810/770/730/700 nm）

灰变化（五波长 ΔA 相等）下按 BB.2~BB.5 计算：

| 衰减增加 | ΔA (OD) | Δc_O₂Hb·L | Δc_HHb·L |
|---|---|---|---|
| 3.0 dB | 0.3000 | **+198.2** μmol/L·cm | **+125.7** μmol/L·cm |
| **3.5 dB** | 0.3500 | **+231.3** | **+146.6** |
| 4.0 dB | 0.4000 | +264.3 | +167.6 |

（分别 = 1.98/1.26、2.31/1.47、2.64/1.68 (mmol/L)·mm）

⚠️ 上表为**理论参考值**，实际以参考系统实测的 I_A、I_B 为准。若实测五波长 ΔA 不完全相等，须逐波长代入求解。

> **BB.1 总则原文**：「功能性近红外光谱设备的制造商并不使用相同的波长，功能性近红外光谱体模引起的光强变化因制造商而异。因此，**不同制造商的路径长度依赖的血红蛋白变化量的参考值可能不同**。」

### 4.6 步骤

1. 按 §2 完成全部前置条件（R1、R2、R4，101.3 峰值波长）
2. 按 §2.4 选定并记录探头组合
3. 按 §3 搭建体模与遮光

**参考系统先测（图 BB.2）**

4. 体模、光源、探测器固定在遮光箱内，**位置一经确定全程不动**
5. 光源预热至稳定，记录 15 min 输出波动
6. 孔径置**状态 A**，逐波长测 I_A，重复 N≥10 次取均值
7. 孔径切**状态 B**，测 I_B，同样 N≥10 次（**切孔径时不要碰体模和探测器**）
8. **切回 A 再测一次**（回差检查），与第 6 步差 >1% 则本轮作废
9. 整个 A→B→A 循环重复 **≥3 次**
10. 按 BB.2 算 ΔA_ref，按 §4.4 算 **x_ref**

**被测设备测（图 BB.3）**

11. 同一块体模、同一位置，只把光源与功率计换成设备的两个探头
12. 孔径 A→B→A，各采集 **≥60 s**，切换时刻打事件标记
13. 重复 **≥5 次**
14. 去掉切换后过渡段（前 10 s），取稳定段均值得 I_A、I_B
15. 按**完全相同**的公式与 E 矩阵算 **x_dev**

**比较**

16. 计算相对偏差，判 A1~A4

> ⚠️ **不要用在线管线跑此试验。** `intensities_to_od_changes` 在 `refs=None` 时用本段时间均值做参考，因果模式下用热身窗冻结基线，**两者都不是"状态 A 相对状态 B"**；带通滤波还会削掉阶跃。**应记录原始光强后离线计算。**
>
> ⚠️ **量纲统一**：`generalized_mbll` 中 `a_hb = hb_ex * pathlength[:,None]`，会除以 `pathlength = DPF × distance_cm` 输出摩尔浓度 Δc（μM）；而标准的被测量是 **Δc·L**。比较前须乘回 L(λ)，或两侧使用同一 pathlength（只要一致即抵消，**记录所用数值**）。
>
> ⚠️ **ε 与波长必须两侧一致**：参考侧与设备侧须用同一份消光系数表和同一组（101.3 实测的）峰值波长。

### 4.7 判据

| 序号 | 判据 | 出处 |
|---|---|---|
| **A1** | **设备值与参考值的差值 <5%**（HbO、HbR 各算一个，均须合格） | **BB.3.1 规范性判据** |
| A2 | 五波长实测 ΔA(λ) 与参考值的逐波长偏差 ≤10%（**波长间增益一致性**） | 自定 |
| A3 | ΔHbO·L 与 ΔHbR·L **同向**；A→B 双双为正，B→A 双双为负 | BB.3.1 注 1 |
| A4 | 5 次重复的 CV ≤10% | 自定 |

**顺带校验**（记录在案，反映体模质量）：

| 校验 | 判据 | 意义 |
|---|---|---|
| 五波长 ΔA_ref 一致性 | CV ≤1% | 孔径为几何机制，各波长应相同；偏差反映漫化是否充分 |
| ΔA 均值 vs log₁₀(孔径面积比) | 差 ≤5% | 核对 BB.3.1 的几何溯源关系成立 |
| 回差（A→B→A） | ≤1% | 光源稳定性 |

---

## 5. 【101.6】信号稳定性

**装置**：发射探头 →〔衰减器 6〕→ 接收探头（图 201.104）。

> **101.6 b) 原文**：「衰减器由**滤光片**或散射、吸收的衰减材料制成，对**每一适用波长**有大于 40 dB 的光损耗。光损耗是预先用**光功率计**测量的，或者，**如果是滤光片，则用分光光度计测量**。」

**步骤**：c) 充分预热 → d) **功率设为最大** → e) **连续采集 >15 min**，用**时间常数 <5 s 的低通滤波器**处理 → f) 针对氧合与脱氧血红蛋白分别计算。

**公式（2）**：

$$S_{stab} = \sqrt{\frac{\sum_{j=1}^{k}\left\{(\Delta c\cdot L)_j - \overline{\Delta c\cdot L}\right\}^2}{k-1}},\qquad \overline{\Delta c\cdot L}=\frac{\sum_{j=1}^{k}(\Delta c\cdot L)_j}{k}$$

k 为时间序列中样本的个数。**即 Δc·L 时间序列的样本标准差**——衰减器全程不变，测的是设备自身的漂移与噪声。

> **原文注**：「Δc·L 与基线样本的变化有关，而与衰减的变化无关。」

**取氧合与脱氧血红蛋白两者中 S_stab 的较大值作为信号稳定性。**

| 序号 | 判据 |
|---|---|
| **B1** | 测量 S_stab 并**在使用说明书中给出**（标准不设限值） |

---

## 6. 【101.7】响应时间

**装置**：发射探头 →〔衰减器｜**光学快门**｜衰减器〕→ 接收探头（图 201.105）。快门关闭时光损耗无穷大，开启时 >40 dB。

⚠️ **快门切换时间应小于 ME 设备的响应时间**（GB 版新增，201.12.1.107）。

**方法**：测快门切换引起的 Δc·L 阶跃响应，取幅度在 **10% 与 90% 之间**的时间间隔（图 201.106）。

| 序号 | 判据 |
|---|---|
| **C1** | 测量响应时间（上升时间/下降时间）并在使用说明书中给出 |

⚠️ **当前配对采样率约 1 Hz**，时间分辨率 1000 ms；且 `BP_HIGH_HZ = 0.1` 的带通会进一步拖慢阶跃。**按实测值如实报告。**

---

## 7. 【101.8】信噪比

**装置**：ME 设备 + 一个光学孔径 + 两个衰减器（图 201.107）。

| 状态 | 光损耗 |
|---|---|
| A | **>60 dB** |
| B | 比 A **大 3~4 dB** |

**步骤**：c) **ME 设备处于最高采样率**；信号变化应进行 **≥4 次重复测量**，每次包括 **≥10 个采样点**。

**公式（3）、（4）**：

$$S_A=\overline{\Delta c\cdot L_A}=\frac{\sum_{j=1}^{m}(\Delta c\cdot L)_{j,A}}{m},\qquad S_B=\frac{\sum_{j=1}^{m}(\Delta c\cdot L)_{j,B}}{m}$$

$$S = S_A - S_B$$

$$\delta S = \sqrt{\frac{\sum_{i=1}^{n}\left(\sum_{j=1}^{m}\left\{(\Delta c\cdot L)_{j,A} - \overline{\Delta c\cdot L_A}\right\}^2\right)}{m\cdot n - 1}}$$

$$\text{信噪比} = S/\delta S$$

m 为采样事件数（≥10），n 为重复次数（≥4）。

> ⚠️ **必须使用 GB 版公式**。GB 9706.271 前言载明：「更改了信噪比中标准差 δS 的计算公式（见 201.12.1.101.8），**国际标准公式编辑错误，对其进行更正**」。
>
> **注意本项为"自比"结构**：(Δc·L) 全部来自 ME 设备自身输出，功率计不参与，检的是响应的稳定性与可重复性。

**101.8 e)**：通过测量得到路径长度依赖的血红蛋白变化量、路径长度依赖的**氧合**血红蛋白变化量和路径长度依赖的**脱氧**血红蛋白变化量。

| 序号 | 判据 |
|---|---|
| **D1** | 测量信噪比并在使用说明书中给出 |
| **D2** | **同时声称最大采样率**（标准强制） |

---

## 8. 记录与报告

### 8.1 每次试验记录

- **探头组合**（§2.4 表格，强制）
- **参考系统的仪器编号与校准证书号**
- 原始光强（`all_groups.csv`）、配对光强（`interleaved_output_ch{n}.csv`）、浓度输出（`processed_output_ch{n}.csv`）
- 试验条件：环境温湿度、体模状态与实测光损耗、各探测器增益档
- **事件时间标记**：孔径切换、快门动作时刻
- 101.3 实测峰值波长与所用 ε 取值

### 8.2 报告应给出

1. 各判据（R1~R2、R4、A1~A4、B1、C1、D1~D2）的实测值与通过/不通过结论
2. 全部曲线图
3. **测量量的定义与假设声明**（必写）：

> 本方法验证路径长度依赖的血红蛋白变化量 Δc·L 的幅度准确度。**平均光程 L 为假设值**（DPF 公式与年龄参数已在说明书披露），**不在本试验验证范围内**。

4. **验证边界声明**（必写）：

> 本试验采用 GB 9706.271—2022 附录 BB 的变孔径体模。该体模产生的光强变化在各波长上相同，据 BB.3.1 注 1，解出的 Δc_O₂Hb·L 与 Δc_HHb·L **同号**；据注 3，其大小与方向**与人体脑激活不同**。本试验验证的是设备对已知光强变化的**数值准确度**（<5%），不涵盖生理条件下的方向性。

5. **BB.5 更正说明**（必写）：

> 计算中 Δc_HHb·L 采用克拉默法则形式（等价于 pinv 最小二乘解）。GB 9706.271—2022 公式 BB.5 印刷的分子两项次序与其自身算例（BB.3.1，结果 +111 μmol/L·cm，注 1 载明"均为阳性"）不符，直接实现会导致符号相反。

6. **参考系统适配说明**（若采用 §3.3 的 LED 适配方案，必写）

---

## 附 A：公式汇总

| # | 公式 | 出处 | 用途 |
|---|---|---|---|
| 1 | S_apB/S_apA = I_B/I_A | BB.3.1 | 孔径面积比 = 光强比，溯源基础 |
| 2 | I_B/I_A = exp[−Δμa·L] | BB.1 | 修正比尔-朗伯的指数形式 |
| 3 | ΔA(λ) = log₁₀[I_A/I_B] | BB.2 | 衰减变化定义（I₀ 在此约掉） |
| 4 | ΔA(λ) = ε_O₂Hb·Δc_O₂Hb·L + ε_HHb·Δc_HHb·L | BB.3 | MBLL 展开 |
| 5 | Δc_O₂Hb·L 闭式解 | BB.4 | 双波长解 |
| 6 | Δc_HHb·L 闭式解 ⚠️**原文有误，见 §4.3** | BB.5 | 双波长解 |
| 7 | x = pinv(E)·ΔA | BB.4/.5 推广 | 五波长最小二乘解（**推荐，天然正确**） |
| 8 | OL = P_ex,total/P_in，OL_dB = 10log₁₀(OL) | BB.6 | 光损耗 |
| 9 | S_stab = √[Σ(Δc·L − mean)²/(k−1)] | 公式 2 | 信号稳定性 |
| 10 | δS、S = S_A − S_B、SNR = S/δS | 公式 3、4 | 信噪比（**用 GB 版**） |
| 11 | P_av = P_peak × τ × f | 公式 1 | 脉冲平均光功率 |
| — | X dB 光损耗 = 透过比例 10^(−X/10)；1 OD = 10 dB | 3.209 | 单位换算 |

---

## 附 B：判据编号索引

| 编号 | 所属 | 性质 |
|---|---|---|
| R1~R2 | §2.1 增益整定与饱和排查 | 前置条件，自定 |
| R4 | §2.2 遮光验证 | 前置条件，自定 |
| **A1** | §4.7 血红蛋白变化量（101.5） | **规范性，<5%** |
| A2~A4 | §4.7 | 自定 |
| B1 | §5 信号稳定性（101.6） | 声称项 |
| C1 | §6 响应时间（101.7） | 声称项 |
| D1~D2 | §7 信噪比（101.8） | 声称项 |

---

## 附 C：出处

### 标准原文

| 内容 | 出处 |
|---|---|
| 探头组合的选择与记录 | GB 9706.271—2022 **201.12.1.101.1** |
| 平均光功率、峰值波长、FWHM；公式 1 | **201.12.1.101.2 / .3 / .4**，图 201.102、201.103 |
| 血红蛋白变化量试验（全文指向附录 BB） | **201.12.1.101.5** |
| Δc·L 为官方测量量、L 不可单独测得、BB.1~BB.5 | **附录 BB.2**（规范性） |
| 透射法的理由、孔径面积比关系、参考系统组成、**<5% 判据**、算例与注 1/注 3 | **附录 BB.3.1**，图 201.BB.1、图 BB.2、图 BB.3 |
| 光损耗测量、40/60 dB、3~4 dB、8 mm 出口孔径、BB.6 | **附录 BB.3.2** |
| 信号稳定性试验与公式 2；衰减器可为滤光片、用分光光度计测 | **201.12.1.101.6**，图 201.104 |
| 响应时间与 10%~90% 定义 | **201.12.1.101.7**，图 201.105、201.106 |
| 快门切换时间要求（GB 版新增） | **201.12.1.107** |
| 信噪比试验与公式 3、4（GB 版已更正国际标准的编辑错误） | **201.12.1.101.8**，图 201.107 |
| 体模/衰减器的光损耗要求汇总表 | **表 201.101** |
| 光损耗定义（X dB = 10^(−X/10)，用光功率计测量） | GB/T 44423—2024 **3.7**（源自 GB 9706.271 201.3.209） |

### 参考资料

| 内容 | 出处 |
|---|---|
| 符合 IEC 80601-2-71 的商品体模 | [BioPixS fNIRS Phantom](https://biopixstandards.com/products/fnirs-phantom/) |
| 体模实现与使用（滑动条式可变孔径原型） | [PMC12680081](https://pmc.ncbi.nlm.nih.gov/articles/PMC12680081/) |

### 本项目实测

| 内容 | 说明 |
|---|---|
| 长距饱和（std/mean = 0.00043） | `result_table/2026-07-16_15-52-29`，ch2 |
| §4.3 BB.5 符号核验、§4.5 五波长参考值、cond(E) = 3.58 | 以 `tables/wray.csv` 与 `get_dpf()` 实算 |
| 两通道结构（ch1 / ch2 与探测器、波长正交） | `config.py:205` `ACQUISITION_CHANNELS` |

---

## 附 D：实施注意事项

1. **§2.4 的三个同步问题必须先确认**，尤其第 2 条（能否只点 ch1 光源），它决定走跨通道还是做分体工装。
2. **§2.1 增益整定是所有硬件试验的前提**。当前长距 std/mean = 0.00043 属饱和，此时下游读数全部无效。
3. **各探测器须支持独立增益档位**——101.5 的 >40 dB 与 101.8 的 >60 dB 信号量级相差百倍，共用一档无法覆盖。
4. **增益变更后贴肤检测阈值全部作废**，须重标。
5. **101.3 峰值波长必须最先测**，其结果决定 ε 查表取值，影响全部定量结果。
6. **BB.5 按原文实现会使 HbR 反号**——用 `pinv` 规避，并在报告中声明（§8.2 第 5 条）。
7. **参考侧与设备侧必须用同一份 ε 表、同一组波长、同一 pathlength 约定**，否则比较失去意义。
8. **当前有效采样率约 1 Hz**。101.8 要求声称最大采样率，此数值将写入说明书。
9. **自定判据（A2、A4、R1 等）为建议值**，送检前应自行试跑一轮，将明显不可达或过于宽松的数值调整到合理区间。
10. **§8.2 第 3、4、5 条为必写内容**，它们界定了本方法的验证边界。

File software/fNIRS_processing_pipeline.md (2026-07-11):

# 双接收源五波长 fNIRS 处理链路说明

本文档说明当前 `software/fNIRS_processing.py` → `fnirs_pipeline` 的处理链路。
当前版本采用 **双接收源（S1_D1 长距 / S1_D2 短距）+ 五波长（850/810/770/730/700 nm）** 几何，
数据经 **安卓 TCP 桥接** 进入 PC 解码端，最终反演 **HbO / HbR / Cyt** 三色团浓度并估算 **rSO₂**。

> 旧版为单通道双波长（660/940）+ 本地串口直连，本文档不再描述该路径，
> 相关脚本（`adc_live.py` 等）仅作历史保留。

---

## 1. 总览

```text
安卓 App（独占 UART 启停）
  -> TCP/JSON 转发设备串口字节（serial_data, base64）
  -> PC 作为 TCP Server 被动接收（HostTcpSerialBridge）
  -> FrameReader 从字节流同步 26B 数据帧（帧头/长度/checksum）
  -> parse_data_frame -> DataSample(detector_code, wavelength_code, value)
  -> capture_data
       ├─ 写 all_groups.csv
       └─ online_session.feed_sample（喂给在线分析缓冲）
  -> prepare_interleaved_dataframe
       -> butter_lowpass_filter（按 Detector/Wavelength 分组）
       -> sliding_window_rms（按段 RMS）
       -> aggregate_wavelength_cycles（凑齐 2×5 成一行）
       -> interleaved_output.csv
  -> process_csv_dataset
       -> compute_all_channel_concentrations
            ├─ intensities_to_od_changes（每个接收源）
            ├─ smart_bandpass（降采样 + 带通）
            ├─ short_separation_regression（短距校正长距 -> *_ssr）
            └─ generalized_mbll（HbO/HbR + 残差投影 Cyt）
       -> select_output_series（取 config.OUTPUT_CHANNEL）
       -> processed_output.csv
       -> summarize_processed_concentrations（+ rSO₂ 摘要）

并行：OnlineAnalysisWorker 每 ~1s 对【全会话】重算一次，
      经 reporter 把整段 HbO/HbR/Cyt/rSO₂ 回传安卓（replace_full_series=true），
      并镜像写 android_live_output.csv。
```

---

## 2. 传输与协议层

### 2.1 安卓 TCP 桥接（`online_android/tcp_bridge.py`）

- PC 监听 `HOST_TCP_LISTEN_HOST:HOST_TCP_DEFAULT_PORT`（默认 `0.0.0.0:9000`），安卓主动连接
- 消息为 `4 字节大端长度 + UTF-8 JSON`，字段：`ver / type / seq / ts_ms / body`
- 关键消息类型：
  - `hello` / `hello_ack`：握手
  - `serial_data`：安卓上行，`body.payload_b64` 为 base64 的设备串口字节
  - `heartbeat`：心跳
  - `bye` / `bye_ack`：安卓请求结束采集（PC 置 `capture_finished`）
  - `live_analysis_batch` / `analysis_result`：PC 下行的分析结果
- `HostTcpSerialBridge` 把收到的串口字节缓存，并暴露 `read()` / `in_waiting`，从而对上层伪装成一个串口对象

### 2.2 26B 帧格式（`config.py` / `protocol.py`）

- 帧头：`0x55 0xAA`，固定帧长：`0x1A`（26B），payload `21B`
- 类型：`0x01` 指令帧 / `0x02` 数据帧 / `0x03` 应答帧
- 校验：从 **长度字节** 累加到 **payload 末尾** 的低字节
- ACK：当前固件不回 ACK，`send_frame_with_ack` 直接返回 True（启停由安卓侧控制）

### 2.3 数据帧 `0x02` payload

| 字节 | 含义 |
|---|---|
| 0 | 波长编号：`0x00=未点亮`，`0x01=850`，`0x02=810`，`0x03=770`，`0x04=730`，`0x05=700` nm |
| 1 | 接收源编号：`0x01=S1_D1`，`0x02=S1_D2` |
| 2-5 | 采集值（4 字节大端无符号） |
| 6 | 采集通道编号：`0x01=通道1`，`0x02=通道2`（`0x00`/缺省归入通道1） |
| 7-20 | 保留 |

单帧只携带 **一个采集通道、一个接收源、一个波长下的一次采样值**。
`Wavelength=0x00`（OFF）行在配对前丢弃，不参与 RMS 切段与多波长配对。
**采集通道（byte6）与接收源、波长正交**：PC 先按通道拆分数据流，每个通道内部各有
完整的双接收源×五波长，整条 配对 → SSR → MBLL → rSO₂ 链路在每个通道内各跑一套，
在线/离线结果都按通道分别输出。

---

## 3. 原始采集层（`fnirs_pipeline/capture.py`）

`capture_data()` 的职责：

1. 打开 TCP 桥（`HostTcpSerialBridge`）并等待安卓连接
2. 创建并启动在线分析会话 `create_online_session`
3. 用 `FrameReader` 按帧头同步读取 26B 数据帧
4. 校验通过后 `parse_data_frame` 解出 `DataSample`
5. `feed_sample` 喂给在线缓冲，并把每帧写入 `all_groups.csv`
6. 收到安卓 `bye`（`capture_finished`）或连接关闭时结束采集

### `all_groups.csv` 结构

```text
Time (s),ChannelId,DetectorId,Channel,Wavelength,Value
```

- `Time (s)`：相对接收时间
- `ChannelId`：采集通道编号（`1=通道1`，`2=通道2`；离线按此列拆分成 `*_ch{n}.csv`）
- `DetectorId`：接收源编号（`1=S1_D1`，`2=S1_D2`）
- `Channel`：接收源名（`S1_D1` / `S1_D2`）
- `Wavelength`：波长编号（`0=OFF`，`1..5` 对应五波长；流水线中去掉 `0`）
- `Value`：4 字节采样值

> 离线终算 `run_pipeline` 读入 `all_groups.csv` 后按 `ChannelId` 分组，对每个通道分别写
> `interleaved_output_ch{n}.csv` / `processed_output_ch{n}.csv`，并各发一条带 `channel` 字段的
> `analysis_result`。在线 `OnlineAnalysisWorker` 经 `ChannelDispatcher` 为每个通道各维护一个
> 处理器，逐通道回传 `live_analysis_batch`（含 `channel`）。

---

## 4. 预处理层（`fnirs_pipeline/preprocessing.py`）

入口：`prepare_interleaved_dataframe`
输入：`all_groups.csv`（或在线缓冲快照）
输出：`interleaved_output.csv`

### 4.1 丢弃 OFF 行

`Wavelength == WAVELENGTH_OFF_CODE(0x00)` 的样本先剔除。

### 4.2 低通滤波 `butter_lowpass_filter`

- 按 `(DetectorId, Wavelength)` 分组分别低通，避免不同 LED/PD 电平互相污染
- 数据太短自动跳过，避免 `filtfilt` 报错

### 4.3 分段 RMS `sliding_window_rms`

- 依据 `(DetectorId, Wavelength)` 连续段切段
- 每段把采样值压成一行 RMS 代表值，时间取段内均值
- 目的：用一个稳定值代表同一接收源/波长时隙，便于后续配对

### 4.4 多波长配对 `aggregate_wavelength_cycles`

- 在时序上每凑齐 `DETECTOR_CHANNELS × WAVELENGTH_CHANNELS`（当前 2×5=10 个键）即输出一行
- 一行包含全部 10 个光强列
- 配对完成后按平均步长重建等间隔时间戳（可从 0 起算）

### `interleaved_output.csv` 结构

```text
Time (s),S1_D1_850,S1_D1_810,S1_D1_770,S1_D1_730,S1_D1_700,S1_D2_850,...,S1_D2_700
```

每行表示一组对齐好的「2 接收源 × 5 波长」光强样本。

---

## 5. 后处理层（`fnirs_pipeline/mbll.py`）

入口：`process_csv_dataset`（离线终算）/ `calculate_concentration_series`（在线）
核心：`compute_all_channel_concentrations`
输入：`interleaved_output.csv`
输出：`processed_output.csv`

### 5.1 OD 转换

对每个接收源，按 `WAVELENGTH_CHANNELS` 顺序堆叠为 `(5, N)` 光强矩阵，
再 `nsp.intensities_to_od_changes` 得到 ΔOD。

### 5.2 带通滤波 `smart_bandpass`

- 默认带通 `BP_LOW_HZ ~ BP_HIGH_HZ`（`0.01 ~ 0.1 Hz`），4 阶 SOS
- 高采样率时先降采样到 `BP_TARGET_FS_HZ`（默认 20 Hz）再滤波，最后插值回原长度
- 样本太短时自动跳过

### 5.3 短距回归校正 SSR `short_separation_regression`

- 取距离最小的接收源（`S1_D2`，短距）作为头皮/全身干扰参考
- 对每个波长，用短距 ΔOD 对长距 ΔOD 做最小二乘回归并扣除
- 生成新通道 `S1_D1_ssr`（校正后的长距）

### 5.4 广义 MBLL `generalized_mbll`

分步反演，返回 `(3, N)`，行顺序 HbO / HbR / Cyt：

1. HbO/HbR 消光系数来自 nirsimple 内置表（`wray`），插值到五个波长
2. pathlength = `DPF(波长, 年龄) × 源探距离`
3. 先用 `pinv(A_hb) @ ΔOD` 解出 HbO/HbR
4. 计算 Hb 拟合残差 `ΔOD - A_hb·ΔC_hb`
5. 把 Cyt 基向量投影到 Hb 零空间，再从残差中解出 Cyt（UCL-NIR 差分消光系数）

### 5.5 输出通道选择 `select_output_series`

- 从全部通道结果中取 `config.OUTPUT_CHANNEL`（默认 `S1_D1_ssr`）
- 去除非有限值后写盘

### `processed_output.csv` 结构

列前缀取自 `OUTPUT_CHANNEL`：

```text
Time,S1_D1_ssr_hbo,S1_D1_ssr_hbr,S1_D1_ssr_cyt
```

### 5.6 rSO₂ 摘要 `summarize_processed_concentrations`

- 输出 HbO/HbR/Cyt 均值
- 若基线窗内有样本，附加 rSO₂（见第 7 节）

---

## 6. 在线分析与回传（`online_android/`）

- `OnlineSampleBuffer`：累积本会话全部样本
- `OnlineAnalysisWorker`：每 `update_interval_seconds`（默认 1s）触发一次
- `AndroidReporter.send_live_batch`：经 TCP 回传 `live_analysis_batch`，
  同时镜像写 `android_live_output.csv`，可选 PC 端 `live_plotter` 绘图
- 采集结束 `stop()` 时做一次终算落盘

由 `config.ONLINE_MODE` 选择两种在线分析路线：

### 6.1 `full_replace`（旧逻辑，`IncrementalBatchBuilder`）

- 每 tick 对**全会话**重跑 `prepare_interleaved → calculate_series`（非因果 `sosfiltfilt`）
- 仅当配对行数增加（或强制）时才重算
- 每次发送【整段】曲线并置 `replace_full_series=true`
- 缺点：计算/传输随时长 O(N²)，历史曲线每 tick 被改写，量纲不固定

### 6.2 `causal_incremental`（路线 B，`IncrementalCausalProcessor`，默认）

- **增量配对**：自维护流式分段 RMS + 凑组，原始样本只折叠一次，不再每 tick 重跑 prepare
- **固定基准 I0**：用基线窗均值算 ΔOD，历史不随新数据漂移
- **因果 IIR 带通**：`sosfilt` + 持久 `zi` 状态替代零相位滤波，过去的滤波值不再变
- 短距回归 β、显示锚定基线、rSO₂ 基线在**热身末端**（`causal_warmup_seconds`，默认 60s）一次性冻结
- 热身期：用全量 `calculate_series` 出临时曲线（`replace_full_series=true`、`baseline_ready=false`）
- 冻结后：整段回填一次（replace），随后**只追加新样本**（`replace_full_series=false`），单 tick 成本 O(新样本)
- 回传前对浓度做显示换算：摩尔 × `LIVE_CONC_SCALE`（默认 1e6 → μM），并按 `LIVE_BASELINE_ANCHOR` 减基线窗均值锚定，`unit` 字段随之置 `"uM"`
- 代价：用分段 RMS 直接代表波长时隙、跳过离线那步非因果 1Hz 低通，故**在线结果与离线 `processed_output.csv` 不再逐点一致**——离线终算仍是权威结果；因果滤波有群延迟（相位滞后）

---

## 7. rSO₂ 估算（`online_android/rso2.py`）

`compute_rso2_series` 在固定基线假设下，由 ΔHbO/ΔHbR 估算 rSO₂(%)：

- 基线时段：`[baseline_start_s, baseline_end_s]`（默认 `30~60s`）
- 基线 HbT：`DEFAULT_BASELINE_HBT_uM`（默认 `80 μM`）
- 基线 rSO₂：`DEFAULT_BASELINE_RSO2_PCT`（默认 `65%`）
- 用基线段内 ΔHbO/ΔHbR 均值做校正，得到绝对 HbO/HbR，
  再 `rSO₂ = 100 × HbO_abs / (HbO_abs + HbR_abs)`
- 基线窗内无样本时返回 None

> 注意：基线 HbT 与 rSO₂ 为假设常量而非实测，因此 rSO₂ 反映 **相对趋势**，不是绝对标定值。

---

## 8. 关键配置

位置：`software/config.py`

```text
SERIAL_PORT / BAUD_RATE            # 旧串口脚本兜底
HOST_TCP_DEFAULT_PORT = 9000       # 安卓 TCP 端口
SAMPLING_RATE_HZ = 250.0
DETECTOR_CHANNELS                  # S1_D1@3.0cm, S1_D2@1.0cm
WAVELENGTH_CHANNELS                # 850/810/770/730/700 nm
OUTPUT_CHANNEL = "S1_D1_ssr"       # 输出通道
BP_LOW_HZ=0.01 / BP_HIGH_HZ=0.1 / BP_ORDER=4 / BP_TARGET_FS_HZ=20.0
MBLL_DEFAULT_AGE = 27
ONLINE_MODE = "causal_incremental" # 在线路线: full_replace | causal_incremental
LIVE_CONC_SCALE = 1e6              # 回传安卓前浓度换算: 1e6 → μM
LIVE_CONC_UNIT = "uM"
LIVE_BASELINE_ANCHOR = True        # 减基线窗均值，曲线从 0 起算
CYT_DIFFERENCE_EXTINCTION          # 五波长 Cyt 差分消光系数（UCL-NIR）
```

`config.py` 在导入时自检：波长数 ≥ 3、code/emitter/detector 不重复、
OFF code 不在表内、Cyt 消光系数覆盖全部波长、`OUTPUT_CHANNEL` 合法。

---

## 9. 与旧版的核心差异

| 项目 | 旧版（单通道） | 当前版（双接收五波长） |
|---|---|---|
| 数据来源 | 本地串口直连 | 安卓 TCP 桥接（PC 被动收） |
| 通道数 | 1 路 `S1_D1` | 2 路 `S1_D1`(长) + `S1_D2`(短) |
| 波长 | 660 / 940 | 850 / 810 / 770 / 730 / 700 |
| 配对 | 660/940 两块交错 | 2×5=10 键凑齐成一行 |
| 反演产物 | HbO / HbR | HbO / HbR / Cyt + rSO₂ |
| 头皮干扰 | 无 | 短距回归校正（SSR -> `*_ssr`） |
| 采样值 | 2 字节 | 4 字节大端 |
| 在线分析 | 无 | 后台 worker 全量回传安卓 |
| 原始 CSV | `Time,S1_D1,Wavelength` | `Time,DetectorId,Channel,Wavelength,Value` |

---

## 10. 运行建议

1. 确认 `config.py` 中 `HOST_TCP_DEFAULT_PORT`、`DETECTOR_CHANNELS`、`OUTPUT_CHANNEL` 正确
2. 先启动 `python fNIRS_processing.py`，再让安卓连接并发送 `serial_data`
3. 需要 PC 端实时观察时加 `--live_plot`，排查协议时加 `--tcp_debug`
4. 结果在 `software/result_table/<时间戳>/` 下

如果 `processed_output.csv` 行数太少，优先检查：

- 是否确实收到了 `0x02` 数据帧（看采集日志）
- `Wavelength` 是否在 1..5 之间正常轮转、`DetectorId` 是否覆盖 1 和 2
- 是否能凑齐完整的 2×5 配对周期
- 基线窗（默认 30~60s）内是否有样本（影响 rSO₂）

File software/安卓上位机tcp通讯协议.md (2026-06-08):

# 安卓上位机 TCP 通讯协议

| 项目 | 说明 |
|---|---|
| 协议名称 | Host TCP Protocol |
| 版本 | `1` |
| 字符编码 | UTF-8 JSON |
| 传输 | TCP |
| 关联协议 | 下位机 26B 串口帧协议（`protocol.py` / `config.py`） |

---

## 1. 协议定位

当前版本采用 **安卓主导启停、PC 被动收数并分析** 的流程。

```text
┌────────────┐   JSON + 4B长度头   ┌────────────┐   26B UART帧   ┌────────────┐
│ 解码端 PC   │ ◄────────────────► │ 安卓上位机  │ ◄────────────► │ 下位机      │
│ fNIRS      │                     │ 串口唯一方  │                │            │
└────────────┘                     └────────────┘                └────────────┘
```

原则：

1. 串口只由安卓打开，PC 不直接访问 UART。
2. 安卓本地负责启流/停流，PC 不下发串口启停命令。
3. 安卓把串口读到的原始字节块通过 `serial_data` 发给 PC。
4. PC 在接收 `serial_data` 过程中可周期性发送 `live_analysis_batch`，携带一批 HbO/HbR 曲线点用于实时绘图。
5. 安卓发送 `bye` 表示本次数据流结束；PC 回 `bye_ack` 后做最终汇总分析。
6. PC 最终分析完成后发送 `analysis_result`，携带本次 HbO/HbR 平均值用于测试显示。

---

## 2. 连接角色

| 角色 | 说明 |
|---|---|
| PC 解码端 | TCP Server，默认监听 `0.0.0.0:9000` |
| 安卓上位机 | TCP Client，主动连接 PC 的局域网 IP |

PC 启动：

```powershell
python software/fNIRS_processing.py -tcp_port
```

安卓连接：`PC_IP:9000`。

---

## 3. 应用层成帧

TCP 是字节流，每条 JSON 消息前必须加 4 字节大端长度头。

```text
+-------------------------------+
| body_length uint32 big-endian |
+-------------------------------+
| JSON body UTF-8 bytes         |
+-------------------------------+
```

发送伪代码：

```text
body = UTF8(JSON.stringify(message))
send(uint32_be(len(body)) + body)
```

约束：

- `body_length` 范围：`1` 到 `4_194_304`。
- JSON 根节点必须是对象。
- 一条应用消息只包含一个 JSON 对象。

---

## 4. JSON 公共字段

| 字段 | 类型 | 必填 | 说明 |
|---|---|---|---|
| `ver` | int | 是 | 协议版本，当前固定 `1` |
| `type` | string | 是 | 消息类型 |
| `seq` | int | 是 | 发送方单调递增序号，从 `1` 开始 |
| `ts_ms` | int | 否 | 发送方 Unix 时间戳，毫秒 |
| `body` | object | 是 | 类型相关字段 |

---

## 5. 消息类型

### 5.1 `hello`（安卓 -> PC）

安卓 TCP 连接成功后首包发送。

```json
{
  "ver": 1,
  "type": "hello",
  "seq": 1,
  "ts_ms": 1717234567890,
  "body": {
    "client_id": "fNIRS-Android-1.0",
    "serial_port": "USB0",
    "baud_rate": 115200
  }
}
```

### 5.2 `hello_ack`（PC -> 安卓）

PC 接受会话后回复。

```json
{
  "ver": 1,
  "type": "hello_ack",
  "seq": 1,
  "ts_ms": 1717234567891,
  "body": {
    "server_id": "fNIRS-Decoder-1.0",
    "ok": true
  }
}
```

### 5.3 `serial_data`（安卓 -> PC）

安卓将 `InputStream.read()` 读到的串口原始字节块原样 Base64 后上报。块大小由安卓决定，不要求对齐 26B。

| `body` 字段 | 类型 | 必填 | 说明 |
|---|---|---|---|
| `payload_b64` | string | 是 | 串口原始字节的标准 Base64 |
| `byte_len` | int | 否 | 解码后的字节数，用于校验 |

```json
{
  "ver": 1,
  "type": "serial_data",
  "seq": 100,
  "ts_ms": 1717234568000,
  "body": {
    "payload_b64": "VaqqGgACAAAAAAABAAAAZv8=",
    "byte_len": 26
  }
}
```

PC 处理方式：Base64 解码，追加到接收缓冲区，按第二层 26B 协议找帧头 `55 AA` 并解析 `0x02` 数据帧，写入本次 CSV。

### 5.4 `bye`（安卓 -> PC）

安卓在本次采集结束后发送。典型场景：用户在安卓 UI 点击停流后，安卓停止本次数据流，然后发送 `bye` 通知 PC 开始分析。

```json
{
  "ver": 1,
  "type": "bye",
  "seq": 999,
  "ts_ms": 1717234570000,
  "body": {
    "reason": "user_stop"
  }
}
```

### 5.5 `bye_ack`（PC -> 安卓）

PC 收到 `bye` 后立即回复，表示已经结束采集循环并即将开始分析。

```json
{
  "ver": 1,
  "type": "bye_ack",
  "seq": 2,
  "ts_ms": 1717234570001,
  "body": {
    "ref_seq": 999,
    "ok": true
  }
}
```

### 5.6 `live_analysis_batch`（PC -> 安卓）

PC 在采集过程中周期性发送在线分析结果。该消息用于安卓端实时曲线绘图；每批只包含上次回传后新增的点。

| `body` 字段 | 类型 | 必填 | 说明 |
|---|---|---|---|
| `ok` | bool | 是 | 是否成功生成本批在线结果 |
| `times` | number[] | 成功时是 | 曲线点时间，单位秒，相对本次采集开始 |
| `hbo` | number[] | 成功时是 | 与 `times` 对齐的 HbO 序列 |
| `hbr` | number[] | 成功时是 | 与 `times` 对齐的 HbR 序列 |
| `sample_count` | int | 是 | 本批点数 |
| `window_start_s` | number | 成功时是 | 本次滑动窗口起始时间 |
| `window_end_s` | number | 成功时是 | 本次滑动窗口结束时间 |
| `unit` | string | 成功时是 | 当前为 `a.u.` |
| `message` | string | 否 | 失败或调试说明 |

成功示例：

```json
{
  "ver": 1,
  "type": "live_analysis_batch",
  "seq": 3,
  "ts_ms": 1717234569000,
  "body": {
    "ok": true,
    "times": [30.125, 31.126, 32.127],
    "hbo": [0.0000012, 0.0000014, 0.0000015],
    "hbr": [-0.0000004, -0.0000005, -0.0000006],
    "sample_count": 3,
    "window_start_s": 2.125,
    "window_end_s": 32.127,
    "unit": "a.u."
  }
}
```

说明：

- 在线算法使用滑动窗口，前期数据不足时 PC 可能暂时不发送本消息。
- 安卓端可按 `times[i] / hbo[i] / hbr[i]` 直接追加到曲线。
- 最终准确结果仍以 `analysis_result` 和 `processed_output.csv` 为准。

### 5.7 `analysis_result`（PC -> 安卓）

PC 完成本次后处理后发送一条测试结果，包含 HbO/HbR 平均值。

成功示例：

```json
{
  "ver": 1,
  "type": "analysis_result",
  "seq": 3,
  "ts_ms": 1717234572000,
  "body": {
    "ok": true,
    "mean_hbo": 0.0000123,
    "mean_hbr": -0.0000045,
    "sample_count": 128,
    "unit": "a.u."
  }
}
```

失败示例：

```json
{
  "ver": 1,
  "type": "analysis_result",
  "seq": 3,
  "body": {
    "ok": false,
    "message": "No complete wavelength cycles were formed."
  }
}
```

### 5.8 `heartbeat`（双向，可选）

```json
{
  "ver": 1,
  "type": "heartbeat",
  "seq": 200,
  "body": {}
}
```

### 5.9 `error`（双向）

```json
{
  "ver": 1,
  "type": "error",
  "seq": 50,
  "body": {
    "ref_seq": 10,
    "code": "INVALID_BASE64",
    "message": "payload_b64 is not valid standard Base64"
  }
}
```

建议错误码：`INVALID_JSON`、`INVALID_BASE64`、`LENGTH_MISMATCH`、`UNSUPPORTED_TYPE`、`SERIAL_OPEN_FAILED`、`SERIAL_WRITE_FAILED`、`VERSION_MISMATCH`、`ANALYSIS_FAILED`。

---

## 6. 第二层 26B 串口协议关系

本 TCP 协议不解释下位机数据帧内部字段，只透传串口字节。PC 对 `serial_data` 解码后的字节流按现有 `FrameReader` 逻辑处理。

| 项目 | 值 |
|---|-----|
| 帧头 | `55 AA` |
| 帧长 | 固定 26 字节 |
| 长度字节 | `0x1A` |
| 帧类型 | `0x01` 命令 / `0x02` 数据 / `0x03` ACK |
| 数据 payload[0] | 波长码：`0x00` OFF，`0x01` 940nm，`0x02` 660nm 等 |

启流/停流命令帧由安卓本地生成并写入 UART，PC 不通过 TCP 下发。

---

## 7. 典型业务流程

```mermaid
sequenceDiagram
    participant PC as 解码端 PC
    participant AND as 安卓上位机
    participant DEV as 下位机

    PC->>PC: 监听 0.0.0.0:9000
    AND->>PC: TCP connect
    AND->>PC: hello
    PC->>AND: hello_ack(ok=true)
    AND->>DEV: UI 启流，UART 写 26B 启流命令
    loop 采集
        DEV->>AND: UART 0x02 数据帧
        AND->>PC: serial_data(payload_b64)
        PC->>PC: 缓冲 + 26B 解帧 + 写 CSV + 在线窗口分析
        PC-->>AND: live_analysis_batch(times, hbo, hbr)
    end
    AND->>DEV: UI 停流，UART 写 26B 停流命令
    AND->>PC: bye(reason=user_stop)
    PC->>AND: bye_ack(ok=true)
    PC->>PC: CSV 后处理，计算 HbO/HbR 平均值
    PC->>AND: analysis_result(mean_hbo, mean_hbr)
```

---

## 8. 实现检查清单

安卓：

- [ ] TCP Client 连接 `PC_IP:9000`
- [ ] 连接后发送 `hello`
- [ ] 收到 `hello_ack.ok=true` 后允许 UI 启流
- [ ] 串口 `read()` 到的原始字节用 `serial_data.payload_b64` 上报
- [ ] 采集过程中接收 `live_analysis_batch` 并追加绘图
- [ ] UI 停流后发送 `bye`
- [ ] 接收 `bye_ack`
- [ ] 接收并显示 `analysis_result`
- [ ] 串口或协议错误时发送 `error`

PC：

- [ ] TCP Server 监听
- [ ] 长度头拆包 + JSON 解析
- [ ] `hello` -> `hello_ack`
- [ ] `serial_data` -> 缓冲 -> 26B 解帧 -> CSV
- [ ] 采集过程中周期性发送 `live_analysis_batch`
- [ ] `bye` -> `bye_ack` -> 结束采集 -> 后处理
- [ ] 后处理完成 -> `analysis_result`
- [ ] 非法包回 `error`

---

## 9. 修订记录

| 日期 | 说明 |
|---|---|
| 2026-06-01 | 初稿 |
| 2026-06-02 | 精简为安卓主导启停：`hello` / `serial_data` / `bye` / `analysis_result` |
| 2026-06-03 | 增加在线曲线回传：`live_analysis_batch` |

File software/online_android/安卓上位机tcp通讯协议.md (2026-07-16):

# 安卓上位机 TCP 通讯协议

| 项目 | 说明 |
|---|---|
| 协议名称 | Host TCP Protocol |
| 版本 | `1` |
| 字符编码 | UTF-8 JSON |
| 传输 | TCP |
| 关联协议 | 下位机 26B 串口帧协议（`protocol.py` / `config.py`） |

---

## 1. 协议定位

当前版本采用 **安卓主导启停、PC 被动收数并分析** 的流程。

```text
┌────────────┐   JSON + 4B长度头   ┌────────────┐   26B UART帧   ┌────────────┐
│ 解码端 PC   │ ◄────────────────► │ 安卓上位机  │ ◄────────────► │ 下位机      │
│ fNIRS      │                     │ 串口唯一方  │                │            │
└────────────┘                     └────────────┘                └────────────┘
```

原则：

1. 串口只由安卓打开，PC 不直接访问 UART。
2. 安卓本地负责启流/停流，PC 不下发串口启停命令。
3. 安卓把串口读到的原始字节块通过 `serial_data` 发给 PC。
4. PC 在接收 `serial_data` 过程中可周期性发送 `live_analysis_batch`，携带一批 HbO/HbR/rSO2 曲线点用于实时绘图。
5. 安卓发送 `bye` 表示本次数据流结束；PC 回 `bye_ack` 后做最终汇总分析。
6. PC 最终分析完成后发送 `analysis_result`，携带本次 HbO/HbR 平均值用于测试显示。

---

## 2. 连接角色

| 角色 | 说明 |
|---|---|
| PC 解码端 | TCP Server，默认监听 `0.0.0.0:9000` |
| 安卓上位机 | TCP Client，主动连接 PC 的局域网 IP |

PC 启动：

```powershell
python software/fNIRS_processing.py -tcp_port
```

安卓连接：`PC_IP:9000`。

---

## 3. 应用层成帧

TCP 是字节流，每条 JSON 消息前必须加 4 字节大端长度头。

```text
+-------------------------------+
| body_length uint32 big-endian |
+-------------------------------+
| JSON body UTF-8 bytes         |
+-------------------------------+
```

发送伪代码：

```text
body = UTF8(JSON.stringify(message))
send(uint32_be(len(body)) + body)
```

约束：

- `body_length` 范围：`1` 到 `4_194_304`。
- JSON 根节点必须是对象。
- 一条应用消息只包含一个 JSON 对象。

---

## 4. JSON 公共字段

| 字段 | 类型 | 必填 | 说明 |
|---|---|---|---|
| `ver` | int | 是 | 协议版本，当前固定 `1` |
| `type` | string | 是 | 消息类型 |
| `seq` | int | 是 | 发送方单调递增序号，从 `1` 开始 |
| `ts_ms` | int | 否 | 发送方 Unix 时间戳，毫秒 |
| `body` | object | 是 | 类型相关字段 |

---

## 5. 消息类型

### 5.1 `hello`（安卓 -> PC）

安卓 TCP 连接成功后首包发送。

```json
{
  "ver": 1,
  "type": "hello",
  "seq": 1,
  "ts_ms": 1717234567890,
  "body": {
    "client_id": "fNIRS-Android-1.0",
    "serial_port": "USB0",
    "baud_rate": 115200
  }
}
```

### 5.2 `hello_ack`（PC -> 安卓）

PC 接受会话后回复。

```json
{
  "ver": 1,
  "type": "hello_ack",
  "seq": 1,
  "ts_ms": 1717234567891,
  "body": {
    "server_id": "fNIRS-Decoder-1.0",
    "ok": true
  }
}
```

### 5.3 `serial_data`（安卓 -> PC）

安卓将 `InputStream.read()` 读到的串口原始字节块原样 Base64 后上报。块大小由安卓决定，不要求对齐 26B。

| `body` 字段 | 类型 | 必填 | 说明 |
|---|---|---|---|
| `payload_b64` | string | 是 | 串口原始字节的标准 Base64 |
| `byte_len` | int | 否 | 解码后的字节数，用于校验 |

```json
{
  "ver": 1,
  "type": "serial_data",
  "seq": 100,
  "ts_ms": 1717234568000,
  "body": {
    "payload_b64": "VaqqGgACAAAAAAABAAAAZv8=",
    "byte_len": 26
  }
}
```

PC 处理方式：Base64 解码，追加到接收缓冲区，按第二层 26B 协议找帧头 `55 AA` 并解析 `0x02` 数据帧，写入本次 CSV。

### 5.4 `bye`（安卓 -> PC）

安卓在本次采集结束后发送。典型场景：用户在安卓 UI 点击停流后，安卓停止本次数据流，然后发送 `bye` 通知 PC 开始分析。

```json
{
  "ver": 1,
  "type": "bye",
  "seq": 999,
  "ts_ms": 1717234570000,
  "body": {
    "reason": "user_stop"
  }
}
```

### 5.5 `bye_ack`（PC -> 安卓）

PC 收到 `bye` 后立即回复，表示已经结束采集循环并即将开始分析。

```json
{
  "ver": 1,
  "type": "bye_ack",
  "seq": 2,
  "ts_ms": 1717234570001,
  "body": {
    "ref_seq": 999,
    "ok": true
  }
}
```

### 5.5.1 `set_baseline`（安卓 -> PC）

采集中任意时刻，安卓可发送新的 **BL 基线 rSO2（%）**。PC 收到后：

1. 更新运行时 BL 假设；
2. 对**当前已采集的全会话数据**重算 `rso2` / `thi` / `delta_thi`（及 `hbo/hbr/cyt` 在因果模式下同步重算）；
3. 先回 `set_baseline_ack`，再发一批 `live_analysis_batch`（`replace_full_series=true`，整段覆盖曲线）。

| `body` 字段 | 类型 | 必填 | 说明 |
|---|---|---|---|
| `baseline_rso2_pct` | number | 是 | 新 BL 基线 rSO2（%），范围 `1` ~ `99` |
| `baseline_hbt_uM` | number | 否 | 新基线总血红蛋白（µM），缺省沿用当前值（默认 `80`） |

```json
{
  "ver": 1,
  "type": "set_baseline",
  "seq": 50,
  "ts_ms": 1717234568500,
  "body": {
    "baseline_rso2_pct": 68.0,
    "baseline_hbt_uM": 80.0
  }
}
```
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

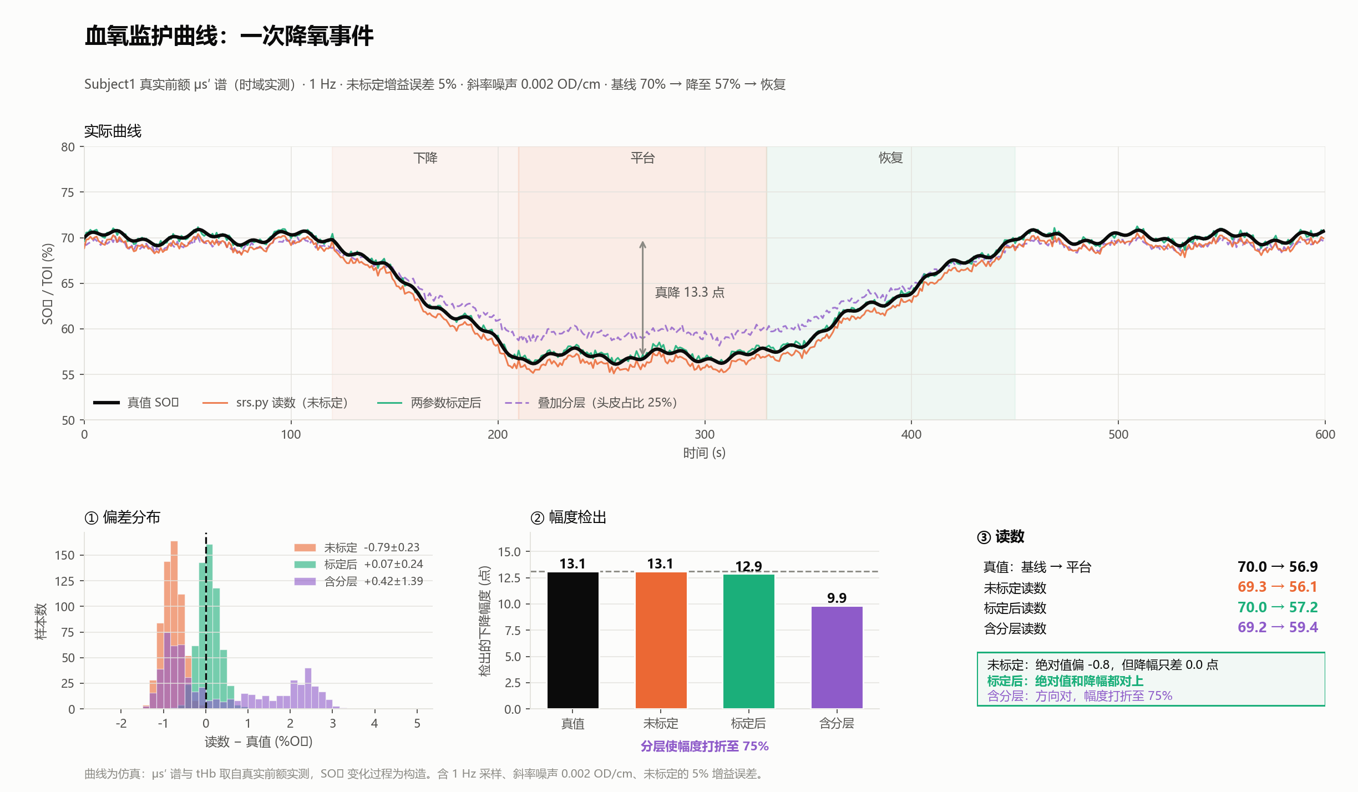
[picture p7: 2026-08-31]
docs/验证图/09_血氧监护曲线.png

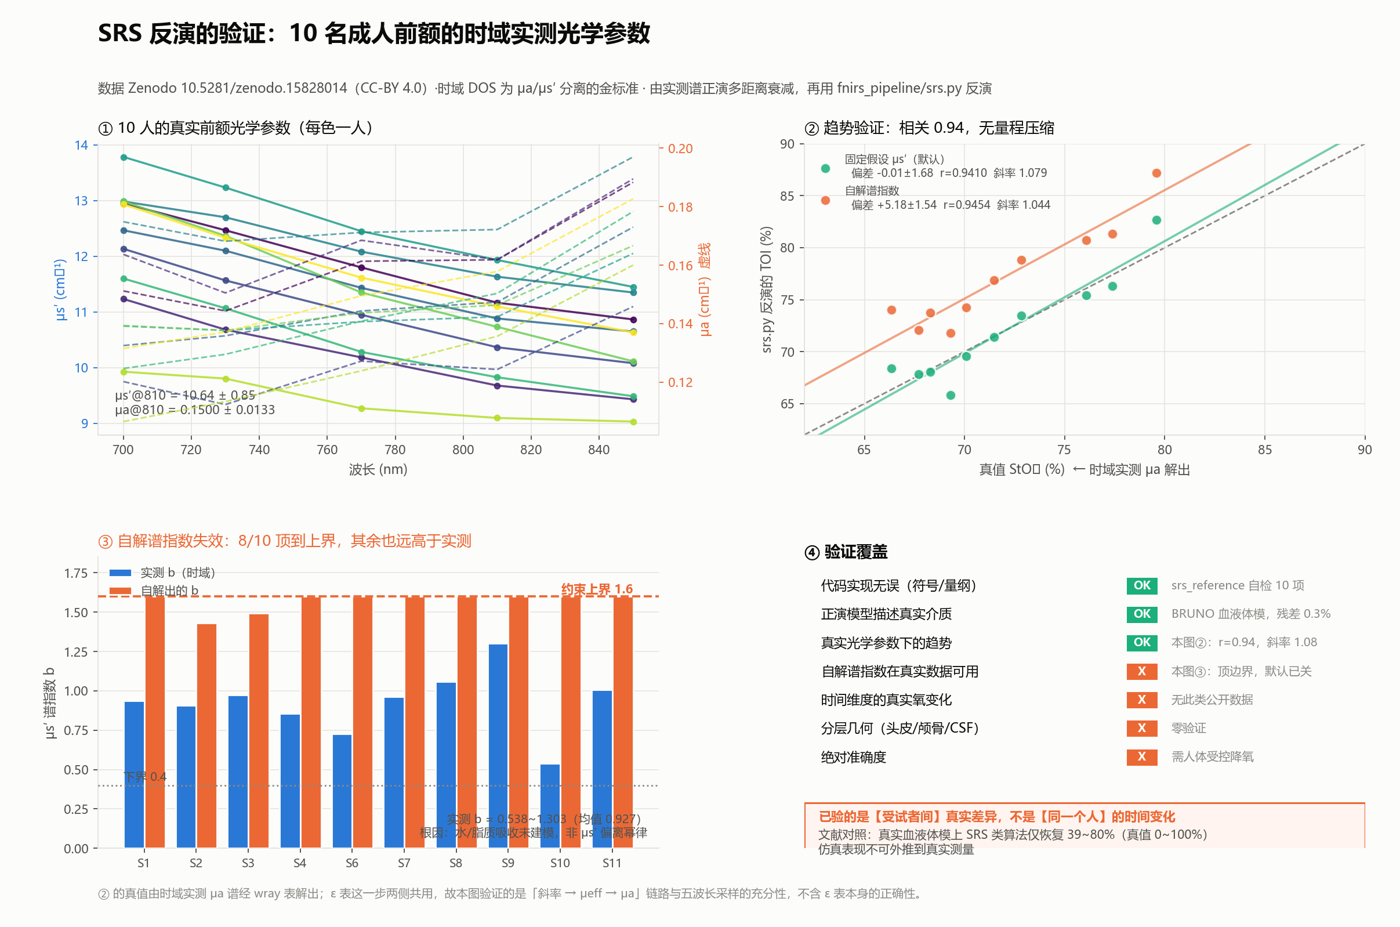
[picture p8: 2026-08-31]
docs/验证图/07_SRS验证.png

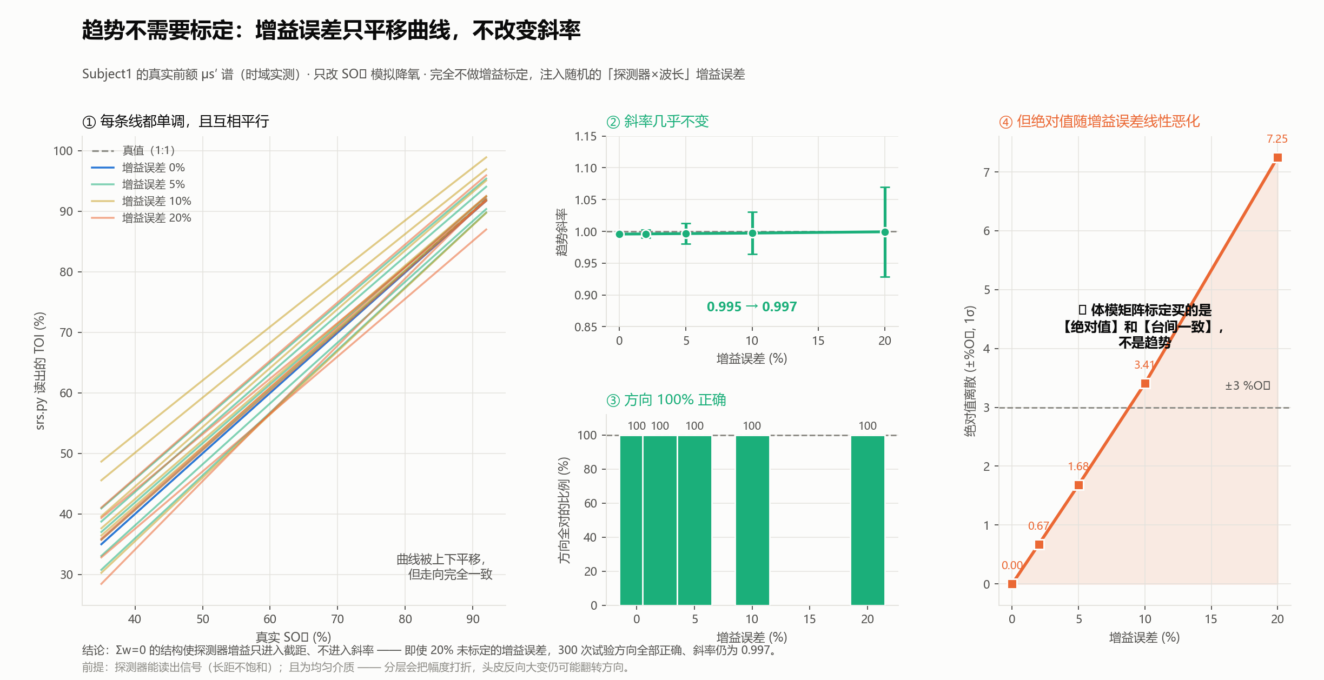
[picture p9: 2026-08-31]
docs/验证图/08_趋势不需标定.png

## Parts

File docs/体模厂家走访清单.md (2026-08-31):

# 体模厂家走访清单

**对象**：上海模辉科技（BestView）
**目的**：核实其测量能力、配方特性、分层与液体体模的实际能力，判断"完整方案"是否适用于 SRS 路线

---

## 0. 先建立一个判断基准

⚠️ **他们的论文（JBP 2026）用的是 DOT 成像思路**——在均匀背景里埋 Φ6mm 腔体，然后成像找出来。

**SRS 不成像，测的是体块平均光学参数。** 两者对体模的要求不同：

| | DOT / 成像 | **SRS** |
|---|---|---|
| 要什么 | 背景 + 小异物（对比度） | **体块均匀 + 已知绝对值** |
| 腔体尺寸 | 小（异物） | **大**（要主导测量体积） |
| 关键指标 | 对比度、位置精度 | **块间一致性、长期稳定性** |

⭐ **开场先问一句**：「你们之前给脑血氧（rSO₂）设备做过标定体模吗？流程是什么样的？」

**答案决定后面怎么谈**——如果他们主要服务成像客户，那"完整方案"需要重新对齐。

---

## 1. 五个决定成败的问题（优先级最高）

### ⭐ Q1：TiO₂ 在 700~850 nm 对 μa 的贡献占多少？

**为什么问**：这是**自标定能否成立**的根源。

各块散射档位不同 → TiO₂ 投料量不同 → 对 μa 的贡献跟着变 → **吸收谱形在块间漂移**。

| TiO₂ 吸收贡献 | 后果 |
|---|---|
| **< 1%** | ✅ 风险消失 |
| ~10% | ❌ 谱形漂移 2% 就使自标定误差超标 **7 倍**，且**残差看不出来** |

**追问**：有没有测过纯 TiO₂ 基体（不加吸收剂）的 μa？

### ⭐ Q2：块间相对精度（重复性）是多少？不是绝对不确定度

**为什么问**：交叉验证的灵敏度完全取决于这个数。

| 块间相对精度 | 能检出 2% 谱形漂移的概率 |
|---|---|
| 5%（IAD 绝对不确定度典型值） | **7.3%** ❌ |
| **1%** | **95.8%** ✅ |

IAD 的 4~5% 绝对不确定度里大部分是系统项（积分球标定、样品厚度、参考白板），**同批测量时是共模、会约掉**。

**要的是同批测量条件下的块间相对精度，目标 ≤1%。**

### ⭐ Q3：能不能做 μs′ ≈ 0.3 cm⁻¹ 的低散射层？

**为什么问**：模拟脑脊液（CSF）。比常规体模低 **30 倍**。

做不到 → 三层退化成两层 → **光管效应验不了**，而那是目前最大的技术未知。

### ⭐ Q4：分层体模叠放时，层间怎么处理？

需要匹配液（甘油/水）还是干贴？空气间隙多厚？

**空气间隙会引入额外界面反射，破坏分层等效性。**

**现场要看**：有没有现成的分层样品，实际叠一下看贴合度。

### ⭐ Q5：血液体模的构型——是留腔还是液体系统？

他们答复过「一般我们留好腔体，你们自己去灌血液」。

⚠️ **Φ6mm 的腔对 SRS 无效**：ρ=3~5cm 的敏感区体积约十余 cm³，Φ6mm 腔只有 0.85 cm³（占比约 5%），**腔内血液降氧几乎不改变体块 μa**。

**要的是液体体模系统**：Intralipid + 全血 + 容器 + 脱氧装置，探头贴壁测。

**问**：做过这种吗？容器构型？还是只做固体腔？

---

## 2. 核实测量能力（决定认证值可信度）

| # | 看什么 / 问什么 |
|---|---|
| 6 | **实地看 IAD + 积分球系统**——光源、探测器、样品架 |
| 7 | 他们的激光器 685/808/830/980，**能不能接 ~30nm 半宽的 LED 作源？**（若能，用我们自己的 LED 标定比窄线宽激光更贴合实际） |
| 8 | 样品厚度怎么控制？IAD 对厚度很敏感 |
| 9 | 参考白板多久标定一次？有没有溯源证书？ |
| 10 | **要一份真实的测试报告样本**（不是宣传册）——看格式、看给不给标准差 |
| 11 | 均一性检测的**原始数据**——他们说"镜检 + 固定位置和随机不同点位测量"，要看数值 |
| 12 | 留样追踪的记录——他们说实验室追踪 8 年，看数据 |

---

## 3. 配方与材料

| # | 问什么 | 为什么 |
|---|---|---|
| 13 | 12 块是不是**同一批次、同一种吸收剂**（不同浓度）？ | 自标定的核心前提 |
| 14 | 吸收剂是什么？（炭黑 / 墨水 / 染料） | 决定 μa 谱形是平坦还是有斜率 |
| 15 | 基体材料？环氧还是别的？ | 折射率 1.42 的来源 |
| 16 | 温度系数（%/°C）？ | 前面三条待追问之一，一直没答 |
| 17 | 固化收缩、气泡控制？ | 影响均一性 |

---

## 4. 带过去的材料

| 文件 | 用途 |
|---|---|
| [`分层体模规格.md`](分层体模规格.md) | 三层的具体参数、厚度、形状，7 件 BOM |
| 五波长 ε 表（wray） | 让他们核算深层的 μa 目标值 |
| 已收到的报价单 | 逐条对齐待补条款 |

**待补进合同的五条**（前面整理过）：
1. A-D / 1-3 的**具体档位数值**，确认覆盖 μa 0.10~0.20、μs′ 8~12 cm⁻¹
2. **「测量标准差」的确切含义**——是绝对不确定度还是块间相对精度
3. **同一吸收剂不同浓度**
4. **TiO₂ 对 μa 的贡献占比**
5. **折射率 1.42** 写进合同

---

## 5. 现场最好能做的两件事

**① 借他们的设备测一块**

如果能带探头去，在他们的样品上实测一次，对比他们的认证值。**这是最快的能力核实。**

**② 看他们给别的脑氧客户做过什么**

不必看具体客户，看**流程文档**：他们的标定服务包含哪些步骤、交付什么。

⚠️ 如果答案是"我们只提供体模，标定你们自己做"——那"完整方案"就是话术，要据此调整期望。

---

## 6. 判断"完整方案"含金量的三个信号

| 信号 | 含义 |
|---|---|
| 能说清 **SRS 和 DOT 对体模要求的区别** | ✅ 真懂 |
| 主动提到**块间一致性**、**长期稳定性**而非只谈绝对精度 | ✅ 真懂 |
| 做过**液体降氧**或**分层**体模的实例 | ✅ 有经验 |
| 只强调"我们数据库上万组""精度高" | ⚠️ 销售话术 |
| 把 SRS 当成 DOT 谈 | ⚠️ 需要重新对齐 |

---

## 附：不要在现场承诺的事

⚠️ **不要当场敲定 3×4 矩阵的订单。**

按前面的分析，优先级排序是：

1. 注册路径咨询（非技术，卡住全废）
2. 修长距饱和
3. FTO 检索
4. **分层体模**（补最大缺口，还能验 SSR）
5. 液体降氧体模
6. 单块 + 功率计验硬件
7. **3×4 矩阵**（风险最低，可最后做）

**矩阵不是分水岭，分层才是。** 现场可以谈，但先把分层体模的能力问清楚再定采购顺序。

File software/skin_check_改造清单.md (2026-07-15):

# 皮肤检查（佩戴质量检测）改造清单

> **文档版本**：2026-07-13 v3  
> **适用仓库**：`fNIRS-main/software`  
> **读者**：PC 开发、安卓开发、测试、产品  
>
> ⚠️ **v3 关键更新**：本文 v2 写于**双通道改造之前**（2026-07-11 才落地双采集通道 ch1/ch2）。
> 现在原始数据、在线回传、离线落盘都已升级为**按采集通道各跑一套**。皮肤检查也**必须按采集通道
> 逐通道评估**（每个采集通道内部仍是完整的 2 接收源 × 5 波长 = 10 路）。凡涉及原始格式、
> `evaluate_skin_check` 接口、`skin_check_result` 协议、PC 编排的地方，v3 均已补上 `ChannelId` /
> `channel` 维度，语义对齐 `live_analysis_batch`（每个采集通道各发一条、按 `channel` 区分）。

---

## 目录

1. [这份文档解决什么问题](#1-这份文档解决什么问题)
2. [和皮肤检查、VOT、正式采集的区别](#2-和皮肤检查vot正式采集的区别)
3. [推荐方案总览](#3-推荐方案总览)
4. [架构：要不要单独做模块](#4-架构要不要单独做模块)
5. [用户流程](#5-用户流程)
6. [检测算法（三层组合）](#6-检测算法三层组合)
7. [TCP 协议扩展](#7-tcp-协议扩展)
8. [PC 端改造清单](#8-pc-端改造清单)
9. [安卓端改造清单](#9-安卓端改造清单)
10. [测试清单](#10-测试清单)
11. [阈值标定](#11-阈值标定)
12. [分阶段计划](#12-分阶段计划)
13. [FAQ](#13-faq)
14. [相关文件索引](#14-相关文件索引)

---

## 1. 这份文档解决什么问题

当前主链路 `fNIRS_processing.py` → `run_pipeline()` 只做：

```text
采集原始光强 → 预处理 → MBLL/SSR → 在线回传 HbO/HbR/Cyt/rSO₂ → 离线落盘
```

**没有**「戴好了没有」的独立步骤。用户贴探头常见问题：

| 现象 | 后果 |
|---|---|
| 探头未贴紧 | 光强低、波动大，MBLL 不可靠 |
| 头发遮挡 | 某路波长无数据，配对失败 |
| **短距 S1_D2 未贴好** | SSR 校正失效，长距结果失真 |
| 漏光 / 饱和 | 光强异常，曲线乱跳 |

**皮肤检查**是在正式开测前，用 **3～5 秒** 短采集判断佩戴质量，并给出可操作的提示（类似 INVOS 的 **SSI 信号强度条**），而不是等采完才发现 `processed_output.csv` 生成失败。

---

## 2. 和皮肤检查、VOT、正式采集的区别

三者不要混为一谈：

| 功能 | 目的 | 时长 | 看几条曲线 | 当前是否已有 |
|---|---|---|---|---|
| **皮肤检查** | 探头是否贴好、每个采集通道 10 路光强是否正常 | 3～5 s | **每采集通道 10 路**（2 接收源 × 5 波长） | ❌ 无 |
| **VOT** | 缺血-再灌注激发试验，算 OS/RS 斜率 | 数分钟 | **1 路** rSO₂（如 `S1_D1_ssr`） | ❌ 无 |
| **正式采集** | 监护 / 实验 / 离线分析 | 用户定 | 在线 HbO/HbR/Cyt/rSO₂（按采集通道各一套） | ✅ 已有 |

> **两个正交的"通道"概念，务必分清（双通道改造后尤其重要）：**
>
> - **接收源**（`DetectorChannel`）：`S1_D1`（长距 3.0 cm）/ `S1_D2`（短距 1.0 cm），用于 SSR。皮肤检查的"10 路"= 2 接收源 × 5 波长。
> - **采集通道**（`AcquisitionChannel`，数据帧 payload byte6 = `ChannelId`）：硬件通道 `ch1`(0x01) / `ch2`(0x02)，与接收源/波长正交。**每个采集通道内部各含完整的 10 路**，反演与皮肤检查都在每个采集通道内各跑一套。
>
> 因此双通道同采时皮肤检查最多要评估 **2 采集通道 × 10 路 = 20 路**，`skin_check_result` 用 `channel` 字段区分 ch1/ch2（与 `live_analysis_batch` 完全一致）。

```text
建议产品流程：

  连接 PC → 皮肤检查（10 路光强）→ 通过 → 正式采集
                                    ↘ 可选：VOT（1 路 rSO₂ + 事件打点）
```

**和 VOT 的关键区别：**

- 皮肤检查看 **原始光强 ADC**，在 MBLL 之前，要快、要逐路反馈。  
- VOT 看 **rSO₂ 随时间变化**，要事件点（充气/放气），通常 **单通道** 即可。  
- 皮肤检查 **必须长距 + 短距都合格**；VOT 分析 **只用一条输出通道**（默认 `S1_D1_ssr`）。

---

## 3. 推荐方案总览

### 3.1 算法：三层组合（不用 SCI/SQI 做主判据）

| 层级 | 检查什么 | 通俗理解 |
|---|---|---|
| **第 1 层** | 光强是否在合理范围 | 有没有「亮到能测、又没亮过头」 |
| **第 2 层** | 3～5 秒内光强是否稳定（CV） | 贴紧了应较稳，松了会乱跳 |
| **第 3 层** | 10 路是否都有数据 | 2 接收源 × 5 波长是否齐全 |

汇总输出（**按采集通道各一份**，用 `channel` 字段区分 ch1/ch2）：

- 每路通道：`pass` / `warn` / `fail` / `missing`  
- 每个接收源：是否通过（**S1_D1 与 S1_D2 都必须过**）  
- 每个采集通道：**SSI 1～5 格** + `ok: true/false`  
- 会话级放行：**所有出现过的采集通道都 `ok=true` 才允许进入正式采集**（安卓聚合，见 [§6.6](#66-ssi-总分1-5-格)）  

### 3.2 分工：PC 算、安卓展示（推荐）

```text
安卓：启流 3～5 s → 发 serial_data → 显示结果、引导调整
PC：  收原始帧 → 按 ChannelId 拆分 → 每采集通道各算 10 路光强/CV → 各回传一条 skin_check_result
```

**不建议**安卓本地再实现一套光强判定（易与 PC 离线标准不一致）。  
**不需要**单独进程或新端口，仍在 `online_android` 包内加模块，共用 TCP 9000。

### 3.3 为什么不用 SCI / SQI？

| 方法 | 原理 | 不适合做默认皮肤检查的原因 |
|---|---|---|
| SCI / SQI | 看信号里 0.5～2.5 Hz 心跳成分 | 需 10～30 s；波长时分复用下单通道采样率不够 |
| 光强 + CV | 看原始 ADC 范围与短时稳定性 | 3～5 s 即可；与现有 `threshold_filter` 思路一致 |

SCI/SQI 可作为 **「深度检查 15～30 s」** 的可选二期功能，不作为默认预检阻塞条件。

---

## 4. 架构：要不要单独做模块

**要专门模块，但不要单独服务。**

```text
online_android/
├── skin_check.py            # 纯算法：evaluate_skin_check()，输入单采集通道 sub_df
├── skin_check_session.py    # 预检状态机：定时评估、按通道拆分、发结果
├── skin_check_reporter.py   # 可选：发 skin_check_result（或并入 reporter.py）
├── tcp_bridge.py            # 只加分发，不写算法
├── buffer.py                  # 复用 OnlineSampleBuffer（已带 ChannelId 列）
├── channel_dispatcher.py      # 参考其"按 ChannelId 拆分、每通道各建处理器"的模式
└── session.py / capture.py    # 编排：先预检 → 再正式采集
```

| 要做 | 不要做 |
|---|---|
| `online_android` 内 2～3 个新文件 | 单独 `skin_check_server.py` |
| **按 `ChannelId` 拆分、每采集通道各评一套**（复用 `ChannelDispatcher` 思路） | 把 ch1/ch2 混成一池算"10 路" |
| 预检阶段不启 `OnlineAnalysisWorker` | 预检跑 MBLL / 回传 `live_analysis_batch` |
| 预检不写正式 `all_groups.csv` | 把逻辑全塞进 `tcp_bridge.py` |

与现有分工对齐：`rso2.py`（算法）→ `worker.py`（调度）→ `reporter.py`（发送）；
按通道拆分则对齐 `channel_dispatcher.py`（每个采集通道各维护一个处理器、逐通道隔离异常）。

---

## 5. 用户流程

```text
┌──────────┐                      ┌──────────┐                      ┌──────────┐
│ 安卓 App │                      │ PC 解码端 │                      │  下位机   │
└────┬─────┘                      └────┬─────┘                      └────┬─────┘
     │  TCP 连接 :9000                 │                                 │
     │ ───── hello ──────────────────> │                                 │
     │ <──── hello_ack ─────────────── │                                 │
     │                                 │                                 │
     │ 【皮肤检查】                     │                                 │
     │ ─ skin_check_start ───────────> │ 进入预检模式                     │
     │ <── skin_check_start_ack ────── │                                 │
     │ UART 启流 3～5 s                │                                 │
     │ ───── serial_data ────────────> │ 缓冲原始帧，不算 MBLL            │
     │ <── skin_check_result ───────── │ 每秒推送（10 路状态 + SSI）       │
     │ UI：红/黄/绿，引导调整           │                                 │
     │                                 │                                 │
     │ ok=true → 点「开始正式采集」     │                                 │
     │ ─ skin_check_done(proceed) ───> │ 退出预检，启在线分析             │
     │                                 │                                 │
     │ 【正式采集】（现有流程）          │                                 │
     │ ───── serial_data ────────────> │ live_analysis_batch …           │
     │ ───── bye ────────────────────> │ analysis_result                 │
```

**要点：**

- 皮肤检查与正式采集可 **同一次 TCP 连接** 完成。  
- 预检失败可重复「启流 → 检查」，无需重连。  
- 通过皮肤检查 **不等于** 能做 VOT；VOT 另立流程（见 FAQ）。

---

## 6. 检测算法（三层组合）

### 6.1 输入

预检窗口内（默认最近 **5 s**）的原始采样，格式同 `all_groups.csv` / `OnlineSampleBuffer.snapshot_all()`
（**双通道改造后为 6 列，`Time (s)` 后多了 `ChannelId`**）：

```text
Time (s), ChannelId, DetectorId, Channel, Wavelength, Value
```

**先按 `ChannelId` 拆成各采集通道（ch1/ch2）**，每个采集通道内部再按 `(DetectorId, Wavelength)` 分为 **10 组**：

| 接收源 | 波长（nm） |
|---|---|
| S1_D1（长距 3.0 cm） | 850 / 810 / 770 / 730 / 700 |
| S1_D2（短距 1.0 cm） | 850 / 810 / 770 / 730 / 700 |

- `Wavelength = 0x00`（OFF）**不参与**计算（与主链路一致）。
- `ChannelId` 归一化沿用 `config.normalize_channel_code`（未知/0x00 归入 `DEFAULT_CHANNEL_CODE`）；`snapshot_all()` 已写入归一化后的 `ChannelId`。
- 列名示例：`S1_D1_850`、`S1_D2_700`（与 `config.intensity_column_for` 一致）。

---

### 6.2 第 1 层：光强门限

每通道算窗口内光强 **中位数** `median(I)`（抗尖峰优于均值）。

| 判定 | 条件 |
|---|---|
| 过低 | `median < LOW` → 脱落、遮挡、头发 |
| 正常 | `LOW ≤ median ≤ HIGH` |
| 过高 | `median > HIGH` → 饱和、漏光 |

**建议初值**（与 `fnirs_pipeline/preprocessing.py` 中 `threshold_filter` 对齐）：

| 配置项 | 默认值 |
|---|---|
| `SKIN_CHECK_INTENSITY_LOW` | `50000` |
| `SKIN_CHECK_INTENSITY_HIGH` | `300000` |

二期可为长距/短距、各波长设独立阈值（见 [§11 阈值标定](#11-阈值标定)）。

---

### 6.3 第 2 层：稳定性 CV

要求用户 **静止 3～5 秒**。每通道：

```text
CV = std(I) / mean(I)
```

| CV | 等级 |
|----|---|
| < 0.02 | 优 |
| 0.02 ~ 0.05 | 可接受 |
| > 0.05 | 差（松动、滑动） |

| 配置项 | 默认值 |
|---|---|
| `SKIN_CHECK_CV_GOOD` | `0.02` |
| `SKIN_CHECK_CV_WARN` | `0.05` |
| `SKIN_CHECK_MIN_SAMPLES` | `5`（少于此不算 CV，判 `insufficient_data`） |

---

### 6.4 第 3 层：通道完整性（硬条件）

- 10 路在窗口内均有样本  
- 每路样本数 ≥ `SKIN_CHECK_MIN_SAMPLES`  
- **S1_D1 五波长全过 且 S1_D2 五波长全过**（短距关系 SSR，不能只验长距）

---

### 6.5 单通道 status 合并

| status | 条件 |
|---|---|
| `pass` | 光强正常 + CV 优或可接受 + 样本够 |
| `warn` | 光强正常但 CV 偏差，或光强在边界附近 |
| `fail` | 光强超限，或 CV 太差 |
| `missing` | 无数据 |
| `insufficient_data` | 有数据但点数 < `MIN_SAMPLES` |

`reason` 字段供安卓显示：`intensity_low`、`intensity_high`、`cv_high`、`no_samples`。

---

### 6.6 SSI 总分（1～5 格）

**SSI 与 `ok` 都是「每个采集通道各算一份」**（ch1 一份、ch2 一份），下表针对**单个采集通道内的 10 路**：

| SSI | 建议条件 |
|-----|---|
| **5** | 10/10 路 `pass`，CV 均 < 0.02，双接收源均过 |
| **4** | 10/10 路 `pass`，CV 可接受 |
| **3** | 8～9 路 pass，或 1 路 warn |
| **2** | 6～7 路 pass，或短距未全过 |
| **1** | 多路 fail / missing |

**单采集通道 `ok: true` 建议：**

```text
SSI >= 4（可配置 SKIN_CHECK_MIN_SSI_PASS）
且 S1_D1 五波长全部 pass
且 S1_D2 五波长全部 pass
```

**会话级放行（安卓聚合）：** 双通道同采时，PC 对 ch1/ch2 **各发一条** `skin_check_result`（各带自己的 `ssi`/`ok`/`channel`）。
安卓「开始正式采集」按钮应在**所有出现过的采集通道都 `ok=true`** 时才启用（只点亮一个通道时，只需该通道通过）。
是否要求两通道都在、以及缺通道如何提示，由安卓按产品策略决定。

---

### 6.7 核心代码接口（建议）

```python
# online_android/skin_check.py

@dataclass(frozen=True)
class SkinCheckSettings:
    window_s: float = 5.0
    intensity_low: float = 50_000
    intensity_high: float = 300_000
    cv_good: float = 0.02
    cv_warn: float = 0.05
    min_samples: int = 5
    min_ssi_pass: int = 4

def evaluate_skin_check(
    channel_df: pd.DataFrame,          # 单个采集通道的 sub_df（已按 ChannelId 拆过）
    settings: SkinCheckSettings | None = None,
) -> dict[str, Any]:
    """对**单个采集通道**评估 10 路，返回该通道 skin_check_result body（不含 channel 字段）。"""

def evaluate_skin_check_all(
    raw_df: pd.DataFrame,              # 含 ChannelId 列的整段快照
    settings: SkinCheckSettings | None = None,
) -> list[tuple[int, dict[str, Any]]]:
    """按 ChannelId 拆分，逐采集通道评估，返回 [(channel_code, body), ...]。

    拆分/排序/未知码兜底复用 ChannelDispatcher._channels_present 同款逻辑；
    逐通道 try/except 隔离异常，一路失败不影响其它通道（对齐 build_all）。
    """
```

- `evaluate_skin_check` 处理**单通道**，便于单测；`evaluate_skin_check_all` 负责按 `ChannelId` 分发。
- 回传时由 reporter 给每条 body 补上 `channel` 字段并各发一条（与 `send_live_batch(channel_code, batch)` 一致）。
- **不调用：** `prepare_interleaved_dataframe`、`process_csv_dataset`、MBLL、SSR。

---

## 7. TCP 协议扩展

在 `online_android/安卓上位机tcp通讯协议.md` 中 **新增** 下列类型（`ver=1`，成帧方式不变：4 字节大端长度 + UTF-8 JSON）。

### 7.1 `skin_check_start`（安卓 → PC）

进入皮肤检查；接下来几秒为预检，非正式实验。

```json
{
  "ver": 1,
  "type": "skin_check_start",
  "seq": 10,
  "ts_ms": 1717234568000,
  "body": {
    "window_s": 5.0,
    "require_both_detectors": true
  }
}
```

| 字段 | 类型 | 必填 | 说明 |
|---|---|---|---|
| `window_s` | number | 否 | 评估窗口，默认 `5.0` |
| `require_both_detectors` | bool | 否 | 是否要求 S1_D1+S1_D2 都过，默认 `true` |

---

### 7.2 `skin_check_start_ack`（PC → 安卓）

```json
{
  "ver": 1,
  "type": "skin_check_start_ack",
  "seq": 5,
  "body": {
    "ref_seq": 10,
    "ok": true,
    "window_s": 5.0,
    "message": ""
  }
}
```

---

### 7.3 `skin_check_result`（PC → 安卓）

**推荐：** PC 在预检期间每 **1 s** 主动推送（安卓无需反复 `request`）。
**双通道同采时每个采集通道各发一条**（各带自己的 `channel`/`ssi`/`ok`），安卓按 `channel` 分别刷新 UI——
与 `live_analysis_batch` 完全一致。

```json
{
  "ver": 1,
  "type": "skin_check_result",
  "seq": 6,
  "ts_ms": 1717234568500,
  "body": {
    "channel": 2,
    "ok": false,
    "ssi": 3,
    "window_s": 5.0,
    "sample_count_total": 1280,
    "message": "",
    "detectors": [
      {"name": "S1_D1", "pass": true, "pass_count": 5, "total": 5},
      {"name": "S1_D2", "pass": false, "pass_count": 3, "total": 5}
    ],
    "channels": [
      {
        "name": "S1_D2_850",
        "detector_id": 2,
        "wavelength_code": 1,
        "intensity_median": 42000,
        "cv": 0.062,
        "sample_count": 58,
        "status": "fail",
        "reason": "intensity_low"
      }
    ],
    "thresholds": {
      "intensity_low": 50000,
      "intensity_high": 300000,
      "cv_good": 0.02,
      "cv_warn": 0.05
    }
  }
}
```

| 字段 | 说明 |
|---|---|
| `channel` | 采集通道：`1`=通道1，`2`=通道2；缺省（旧固件未带通道位）统一为 `1`。多通道时每个通道各发一条本消息 |
| `ok` | **该采集通道**是否合格；会话级放行由安卓聚合所有通道 |
| `ssi` | 1～5，仿 INVOS 信号强度条（该通道内 10 路） |
| `channels[].status` | `pass` / `warn` / `fail` / `missing` / `insufficient_data`（此处 `channels` 指该采集通道内的 10 路光路，勿与采集通道 `channel` 混淆） |
| `channels[].reason` | 失败原因码，安卓映射中文文案 |
| `thresholds` | 当前阈值，便于调试页展示 |

> **命名提醒**：body 里的 `channel`（单数）= **采集通道** ch1/ch2；`channels`（复数）= 该采集通道内的 **10 路光路**（接收源×波长）。二者不同层级，安卓解析时注意区分。

---

### 7.4 `skin_check_done`（安卓 → PC）

```json
{
  "ver": 1,
  "type": "skin_check_done",
  "seq": 20,
  "body": {
    "action": "proceed"
  }
}
```

| `action` | 含义 |
|---|---|
| `proceed` | 预检通过，进入正式采集 |
| `cancel` | 放弃本次会话 |
| `retry` | 重新预检（可选） |

PC 收到 `proceed` 后：退出预检模式，启动 `create_online_session`，打开 `all_groups.csv` 写入。

---

### 7.5 各阶段允许的消息

| 阶段 | 安卓 → PC | PC → 安卓 | 禁止 |
|---|---|---|---|
| 皮肤检查 | `hello`, `skin_check_start`, `serial_data`, `skin_check_done` | `hello_ack`, `skin_check_start_ack`, `skin_check_result` | `live_analysis_batch`, `analysis_result` |
| 正式采集 | `serial_data`, `set_baseline`, `bye` | `live_analysis_batch`, `set_baseline_ack`, `bye_ack`, `analysis_result` | `skin_check_result` |

未知 `type` 仍回 `UNSUPPORTED_TYPE`（与现有一致）。

---

## 8. PC 端改造清单

### 8.1 新建 `online_android/skin_check.py`

- [ ] `SkinCheckSettings` 数据类  
- [ ] `evaluate_skin_check(channel_df) -> dict`（**单采集通道**，10 路）  
- [ ] `evaluate_skin_check_all(raw_df) -> list[(channel_code, dict)]`（按 `ChannelId` 拆分并逐通道评估，异常逐通道隔离）  
- [ ] 过滤 `WAVELENGTH_OFF_CODE`；`ChannelId` 用 `normalize_channel_code` 归一化  
- [ ] 按 `DETECTOR_CHANNELS` × `WAVELENGTH_CHANNELS` 生成 10 路结果  
- [ ] 算 median、CV、status、SSI、`ok`  
- [ ] 单元测试用构造 `DataFrame`（含 `ChannelId` 列，见 [§10](#10-测试清单)）  

### 8.2 新建 `online_android/skin_check_session.py`

- [ ] 状态：`idle` → `skin_checking` → `ready_for_capture`  
- [ ] 复用 `OnlineSampleBuffer`（已带 `ChannelId`），只 `append` 不写 MBLL  
- [ ] 定时器每 `SKIN_CHECK_UPDATE_INTERVAL_S`（默认 1 s）取 `snapshot_recent(window_s)` → `evaluate_skin_check_all`  
- [ ] 对返回的每个 `(channel_code, body)` 各调一次 `send_skin_check_result(channel_code, body)`  
- [ ] 收到 `skin_check_done(proceed)` 后停止定时器，交棒正式 `OnlineCaptureSession`  

### 8.3 修改 `online_android/tcp_bridge.py`

- [ ] `_handle_message` 增加：`skin_check_start`、`skin_check_done`  
- [ ] `send_skin_check_start_ack`、`send_skin_check_result`  
- [ ] 预检模式下：`serial_data` 只写 buffer，**不** 喂 `OnlineAnalysisWorker`  
- [ ] 注册 `skin_check` 回调（模式同 `set_baseline_handler`）  

### 8.4 修改 `fnirs_pipeline/capture.py`

- [ ] 连接后等待/处理 `skin_check_start`（或 CLI `--skin_check` 强制预检）  
- [ ] 预检阶段 **不** 打开正式 `all_groups.csv`（可选写 `skin_check_debug.csv`）  
- [ ] `skin_check_done(proceed)` 后再 `create_online_session` 并写 CSV  

### 8.5 修改 `config.py`

```python
# ---------------------------------------------------------------------------
# 皮肤检查（佩戴质量预检）
# ---------------------------------------------------------------------------
SKIN_CHECK_ENABLED = True
SKIN_CHECK_WINDOW_S = 5.0
SKIN_CHECK_UPDATE_INTERVAL_S = 1.0
SKIN_CHECK_INTENSITY_LOW = 50_000
SKIN_CHECK_INTENSITY_HIGH = 300_000
SKIN_CHECK_CV_GOOD = 0.02
SKIN_CHECK_CV_WARN = 0.05
SKIN_CHECK_MIN_SAMPLES = 5
SKIN_CHECK_MIN_SSI_PASS = 4
```

- [ ] 二期：`SKIN_CHECK_INTENSITY_LOW_S1_D2` 等分通道阈值  

### 8.6 其它

- [ ] `online_android/__init__.py` 导出 `evaluate_skin_check`（按需）  
- [ ] `fNIRS_processing.py` 可选：`--skin_check` / `--no_skin_check`  
- [ ] 更新 `安卓上位机tcp通讯协议.md` 第 5.10～5.13 节与时序图  
- [ ] `README.md` / `fNIRS_processing_pipeline.md` 加预检分支说明（可选）  

### 8.7 与现有代码的关系

| 现有代码 | 关系 |
|---|---|
| `preprocessing.threshold_filter` | 光强上下限 **参考同一量级**，预检不调用该函数改数据 |
| `ChannelDispatcher` | **复用其"按 `ChannelId` 拆分、每采集通道各建处理器、逐通道隔离异常"的模式**（皮肤检查是它的轻量版：不建增量处理器，只逐通道跑 `evaluate_skin_check`） |
| `OnlineSampleBuffer` | 直接复用；`snapshot_recent/all` 已带 `ChannelId` 列，`append` 已收 `acq_channel_code` |
| `config.normalize_channel_code` / `channel_name_for_code` | 归一化采集通道码、生成 `ch1/ch2` 标识，直接复用 |
| `reporter.send_live_batch(channel_code, batch)` | `send_skin_check_result(channel_code, body)` **对齐同款「带 channel 逐通道发」签名** |
| `adc_live.py` | 本地串口看光强，**仅调试**；产品路径走安卓 TCP |
| `OnlineAnalysisWorker` | 预检阶段 **不得启动** |
| `live_analysis_batch` | 预检阶段 **不得发送** |

---

## 9. 安卓端改造清单

### 9.1 UI

- [ ] 「皮肤检查」入口（正式采集前）  
- [ ] **按采集通道分区**：ch1 / ch2 各一块（按 `skin_check_result.channel` 分别维护，与 `live_analysis_batch` 一致；只点亮一个通道时只显示那一块）  
- [ ] 每个采集通道内：**SSI 1～5 格**（可仿 INVOS 绿条）  
- [ ] 每个采集通道内 **两块区域**：S1_D1 / S1_D2，各 5 个波长圆点（绿/黄/红）  
- [ ] 「开始正式采集」按钮：**所有出现过的采集通道都 `ok=true` 才启用**（会话级聚合）  
- [ ] `ok=false` 时根据 `reason` 显示文案，例如：  

| reason | 建议文案 |
|---|---|
| `intensity_low` | 光强过低，请压紧探头 |
| `intensity_high` | 光强过高，请检查漏光或贴合 |
| `cv_high` | 信号不稳定，请保持静止并调整贴合 |
| `no_samples` | 该通道无数据，请拨开头发 |
| `insufficient_data` | 采样不足，请延长预检或检查连接 |

- [ ] `ok=true` 后启用「开始正式采集」  
- [ ] 短距 S1_D2 失败时 **单独高亮**（用户常只关注长距）  
- [ ] 提示：「请贴紧额头，保持静止 5 秒」  

### 9.2 协议

- [ ] 连接后发 `hello`，收 `hello_ack`  
- [ ] 点「皮肤检查」→ UART 启流 → 发 `skin_check_start`  
- [ ] 持续 `serial_data`  
- [ ] 收 `skin_check_result`，刷新 UI  
- [ ] 通过后发 `skin_check_done(action=proceed)`  
- [ ] 正式采集流程不变  

### 9.3 可选

- [ ] 调试模式「跳过皮肤检查」（默认关闭）  
- [ ] 展示 `thresholds` 供现场标定  

---

## 10. 测试清单

### 10.1 单元测试（`skin_check.py`）

`evaluate_skin_check`（单采集通道）：

| 用例 | 期望 |
|---|---|
| 10 路光强 ~17 万，CV 0.01 | `ok=true`, `ssi=5` |
| S1_D2_850 均值 1 万 | 该路 `fail`, `ok=false` |
| 某路 CV 0.08 | `fail` 或 `warn` |
| 仅 S1_D1 五路有数据 | S1_D2 `missing`, `ok=false` |
| 每路仅 2 点 | `insufficient_data` |
| 含 Wavelength=0x00 | 不参与计算 |

`evaluate_skin_check_all`（多采集通道，含 `ChannelId` 列）：

| 用例 | 期望 |
|---|---|
| ch1 全好 + ch2 全好 | 返回 2 条，各 `channel`=1/2、各 `ok=true` |
| ch1 全好 + ch2 某路 fail | 返回 2 条，ch1 `ok=true`、ch2 `ok=false` |
| 仅 ch1 有数据 | 只返回 1 条 `channel=1` |
| 无 `ChannelId` 列（旧格式兜底） | 归入 `DEFAULT_CHANNEL_CODE`，返回 1 条 `channel=1` |
| `ChannelId=0x00`（未带通道位） | 归一化进 `channel=1` |

### 10.2 联调（安卓 + PC）

- [ ] `skin_check_start` → `skin_check_start_ack`  
- [ ] 5 s 内 ≥1 条 `skin_check_result`  
- [ ] **双通道同采：每 tick 收到 ch1、ch2 各一条 `skin_check_result`，`channel` 正确**  
- [ ] **只点亮一个通道：只收到该通道那一条**  
- [ ] 松动探头 → SSI 降、`ok=false`  
- [ ] 贴紧静止 → `ok=true`  
- [ ] **一个通道好、另一个坏：安卓放行按钮保持禁用（会话级需全通道 ok）**  
- [ ] 预检通过后正式采集，`live_analysis_batch` 正常  
- [ ] 预检阶段 **无** `live_analysis_batch`  

### 10.3 回归

- [ ] 不发 `skin_check_start` 时行为与改造前 **完全一致**  
- [ ] `set_baseline`、`bye`、`analysis_result` 不受影响  

---

## 11. 阈值标定

1. 从 `result_table/*/all_groups.csv` 选 **10 次好采集、10 次差采集**（人工标注）。  
2. 对每次预检窗口算 10 路 median、CV，画散点图。  
3. 调整 `INTENSITY_LOW/HIGH`，使好采集多 pass、差采集多 fail。  
4. **长距 S1_D1 与短距 S1_D2 分开标定**（二期）。  
5. 各波长可独立阈值（850 nm 与 700 nm 动态范围不同）。  
6. 定稿写入 `config.py`，`skin_check_result.thresholds` 回传便于安卓对齐。  

本地调试可参考 `adc_live.py` 阈值控件（默认 50000～300000），但产品路径以 TCP 预检为准。

---

## 12. 分阶段计划

### 第一阶段（最小可用，约 1～2 周）

| # | 任务 | 产出 |
|---|---|---|
| 1 | `skin_check.py` | 可单测 |
| 2 | `skin_check_session.py` + `tcp_bridge` 协议 | PC 可 mock 联调 |
| 3 | `capture.py` 预检编排 | 端到端预检 |
| 4 | 安卓 UI + 协议 | 真机演示 |
| 5 | 更新协议 md | 文档同步 |

### 第二阶段

- [ ] 长短距 / 分波长阈值  
- [ ] `skin_check_debug.csv` 落盘  
- [ ] PC `--live_plot` 预检光强条  

### 第三阶段（可选）

- [ ] 延长预检 15～30 s + 简化 SCI  
- [ ] 采集中 SSI 掉格报警（贴合监测）  

---

## 13. FAQ

**Q：皮肤检查和 `threshold_filter` 什么关系？**  
A：思路相同（光强是否合理）。`threshold_filter` 用于离线清洗数据；皮肤检查用于 **采集前** 判断，且增加 CV 与 10 路完整性，**不修改**原始数据。

**Q：预检数据写入 `all_groups.csv` 吗？**  
A：**不建议**写入正式文件。需要排查时可写 `skin_check_debug.csv`。

**Q：皮肤检查和 VOT 能合并吗？**  
A：**不要合并**。皮肤检查 = 10 路光强、3～5 s、贴没贴好；VOT = 1 路 rSO₂、事件点、算 OS/RS。流程上建议：皮肤检查 →（可选）VOT → 正式采集。

**Q：VOT 只要一个通道，皮肤检查呢？**  
A：皮肤检查要 **10 路都过**（含短距 S1_D2），因为 SSR 依赖短距；VOT 分析只用 `OUTPUT_CHANNEL` 一条 rSO₂。

**Q：安卓能自己做皮肤检查吗？**  
A：可以解析 `serial_data` 本地算，但与 PC 标准易分叉。**推荐 PC 算、安卓展示**。

**Q：和 INVOS SSI 一样吗？**  
A：形态类似（1～5 格），但你们是 **10 路近红外光强 + CV**，不是 INVOS 的单一 rSO₂ 信号条；SSI 映射规则需自行标定。

**Q：没有 PC 能预检吗？**  
A：安卓可对原始帧本地算光强门限，但当前产品架构是 **PC 解码端**，无 PC 则只能安卓简化版或不做预检。

**Q：双通道（ch1/ch2）下皮肤检查怎么算？**  
A：**按采集通道各跑一套**，和正式采集的反演一致。PC 先按 `ChannelId` 把原始帧拆成 ch1/ch2，每个采集通道内部再按 2 接收源 × 5 波长评 10 路，各自算 SSI/`ok`，用 `channel` 字段区分后**各发一条** `skin_check_result`。安卓按 `channel` 分区显示，放行按钮要求所有出现过的采集通道都 `ok=true`。

**Q：为什么 body 里既有 `channel` 又有 `channels`？**  
A：`channel`（单数）是**采集通道** ch1/ch2；`channels`（复数）是该采集通道内部的 **10 路光路**（接收源×波长）。两个不同层级，命名沿用了协议既有约定（`live_analysis_batch` 也用单数 `channel` 表示采集通道）。

---

## 14. 相关文件索引

| 文件 | 作用 |
|---|---|
| `fNIRS_processing.py` | 主入口 |
| `config.py` | 几何、波长、阈值（待扩展皮肤检查块） |
| `fnirs_pipeline/capture.py` | TCP 采集编排 |
| `fnirs_pipeline/preprocessing.py` | `threshold_filter` 参考 |
| `online_android/buffer.py` | 原始采样缓冲（含 `ChannelId` 列） |
| `online_android/channel_dispatcher.py` | **按 `ChannelId` 拆分、每采集通道各建处理器的范式**（皮肤检查分发直接对齐） |
| `online_android/tcp_bridge.py` | TCP 协议 |
| `online_android/session.py` | 正式在线分析会话 |
| `online_android/安卓上位机tcp通讯协议.md` | 协议文档（待更新） |
| `adc_live.py` | 本地串口看光强（调试，非产品路径） |

---

## 修订记录

| 日期 | 版本 | 说明 |
|---|---|---|
| 2026-07-06 | v1 | 初稿：三层方案 + PC/安卓清单 + 协议草案 |
| 2026-07-06 | v2 | 重写：明确与 VOT/正式采集边界；PC 算安卓展示；10 路 vs 单通道；模块架构；完整协议与 FAQ |
| 2026-07-13 | v3 | **对齐双通道改造**（2026-07-11 落地）：原始格式补 `ChannelId` 列；皮肤检查改为**按采集通道 ch1/ch2 各评一套**；`evaluate_skin_check` 拆为单通道 + `_all` 分发（复用 `ChannelDispatcher` 范式）；`skin_check_result` 新增 `channel` 字段、逐通道发送；SSI/`ok` 分通道，会话级放行由安卓聚合；补双通道测试用例、FAQ、文件索引 |

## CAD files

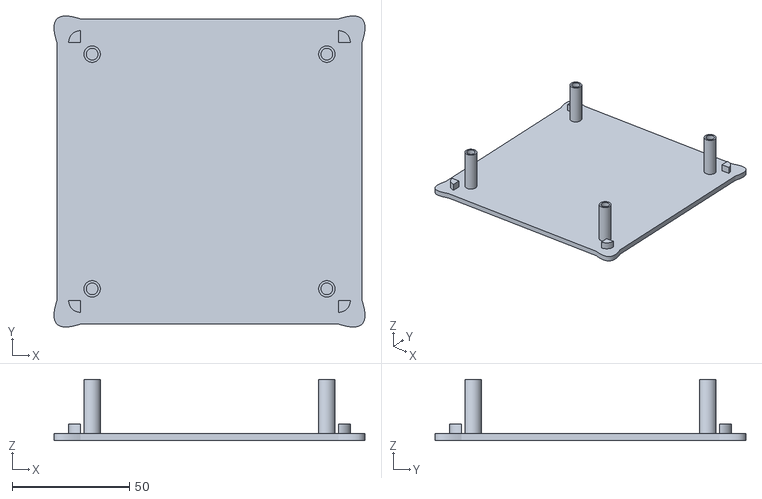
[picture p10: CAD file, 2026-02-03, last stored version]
mechanical/ecu_housing_lid.stl
132.5 x 132.5 x 26.0

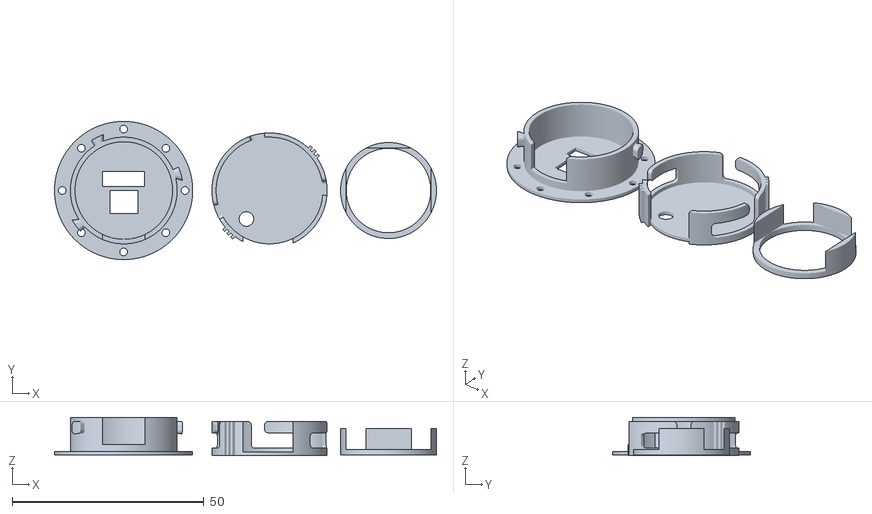
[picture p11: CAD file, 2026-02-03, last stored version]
mechanical/sensor_capsule.stl
99.5 x 36.0 x 9.91

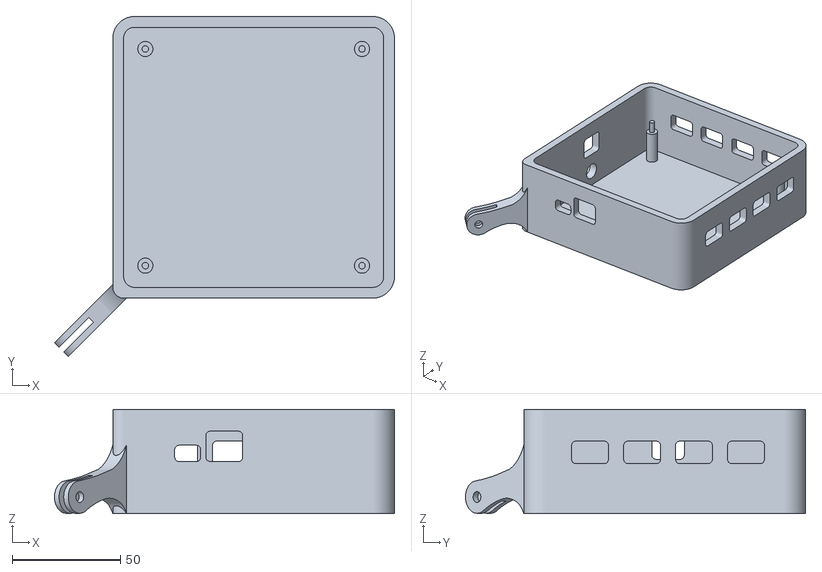
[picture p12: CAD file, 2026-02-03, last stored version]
mechanical/ecu_housing_base.stl
156.9 x 156.9 x 48.0

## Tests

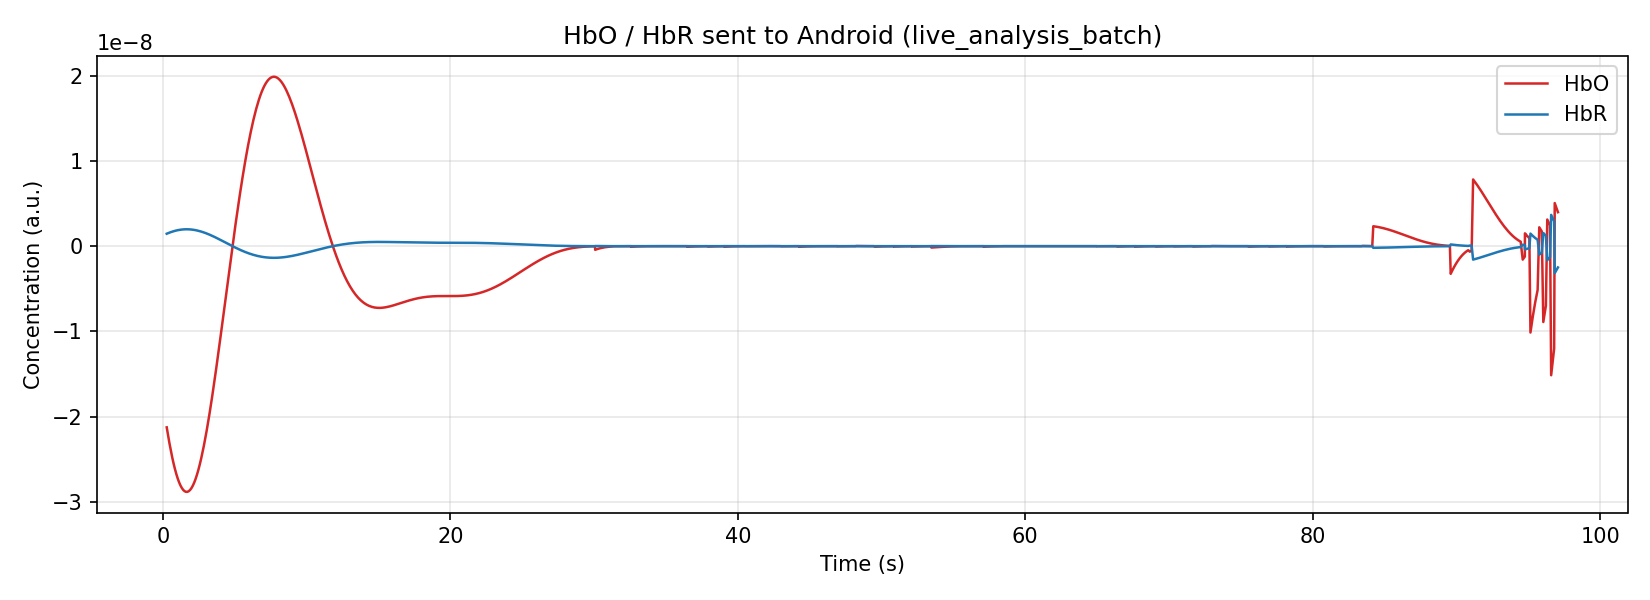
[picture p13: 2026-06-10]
software/result_table/2026-06-08_09-47-53/live_analysis_plot.png

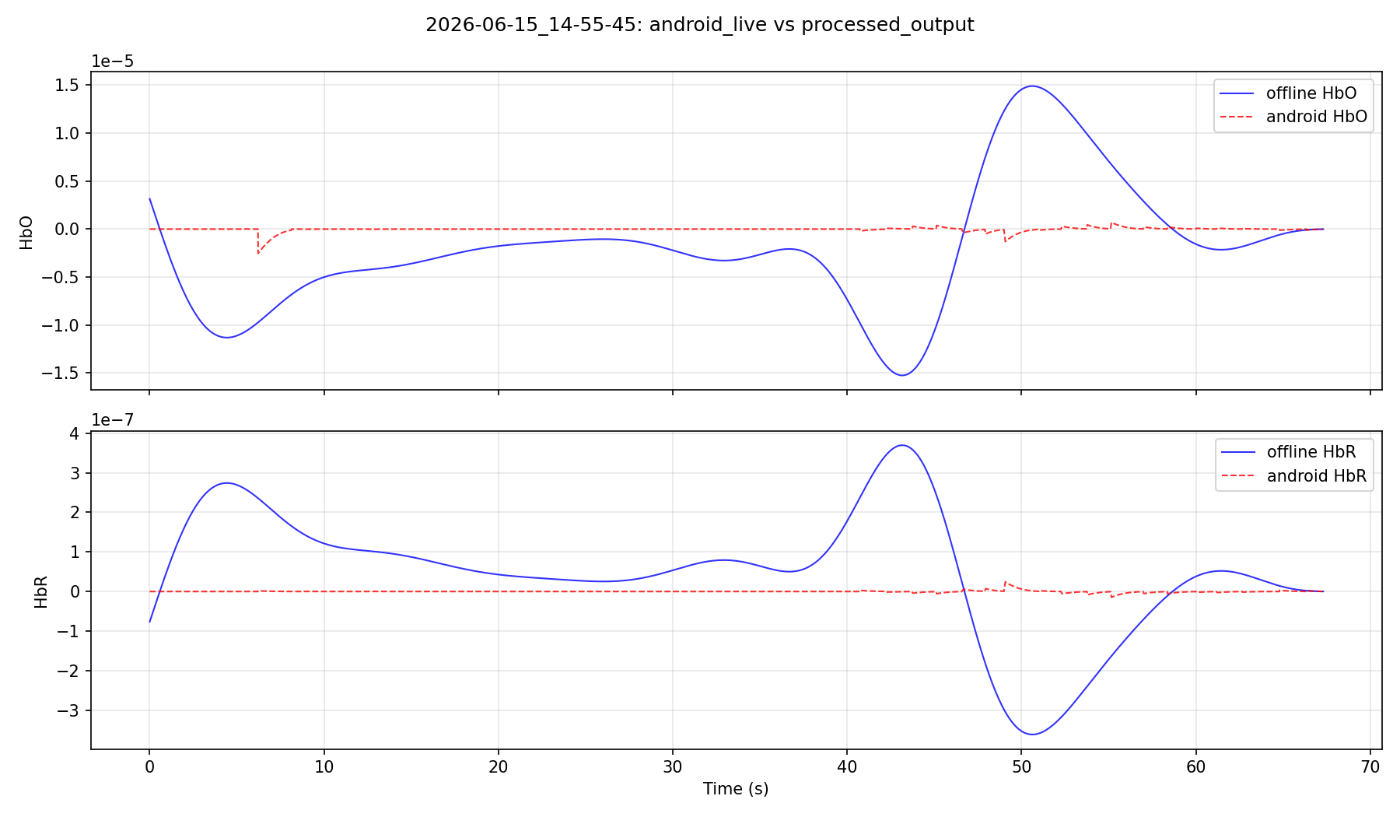
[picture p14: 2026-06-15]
software/result_table/2026-06-15_14-55-45/_compare_android_vs_offline.png

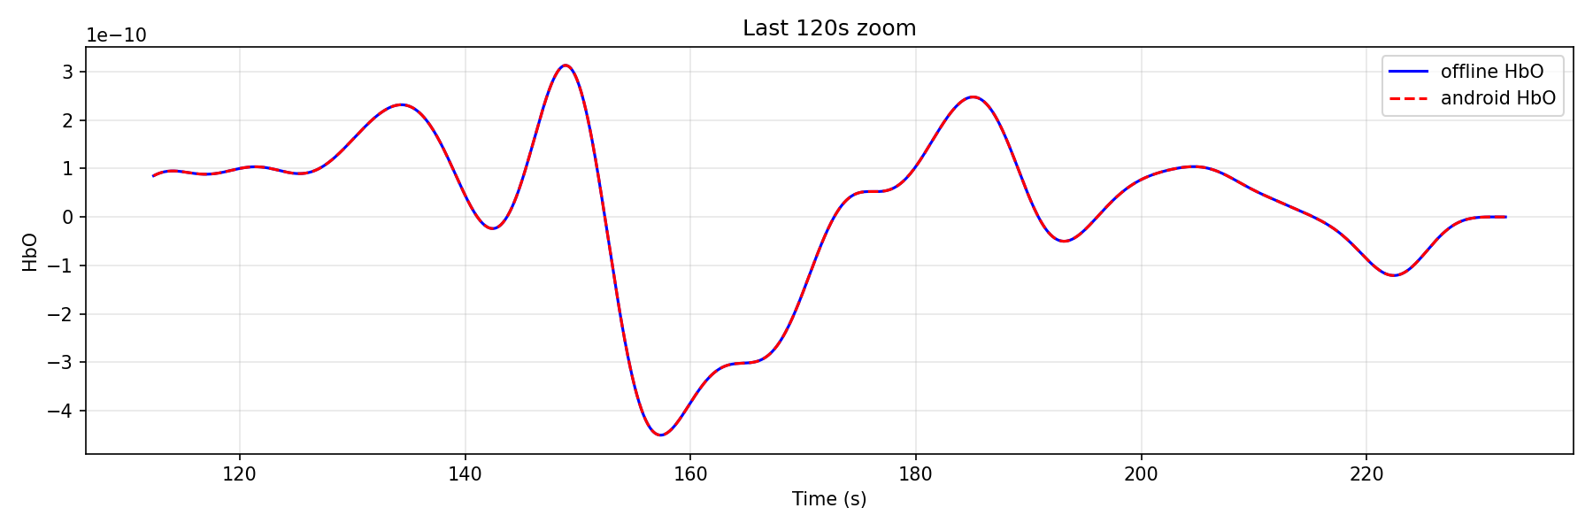
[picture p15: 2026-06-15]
software/result_table/2026-06-15_15-24-45/_compare_zoom_last120s.png

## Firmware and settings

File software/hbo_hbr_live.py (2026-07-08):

"""
单通道实时 HbO / HbR 曲线查看器。

从串口持续读取双波长光强（协议码 0x01 / 0x02），用前几秒建立基线，再对每个波长对做 OD 与 MBLL，
将得到的 HbO、HbR 实时画在坐标图上。MBLL 波长与 data_analysis.py 一致：860 nm + 660 nm；
OD 矩阵行顺序与 data_analysis 相同（Wavelength=1 在上，Wavelength=2 在下）。带通 0.05–0.5 Hz；不做 CBSI。
"""

from __future__ import annotations

import sys
import time
from collections import deque

import numpy as np
from fnirs_pipeline.mbll_core import get_dpf, mbll_hbo_hbr
import pyqtgraph as pg
import serial
from PyQt5 import QtCore, QtWidgets
from scipy.signal import butter, resample_poly, sosfiltfilt

from config import (
    ACK_TIMEOUT_SECONDS,
    BAUD_RATE,
    CHANNEL_NAME,
    DEFAULT_INTENSITY_MA,
    MAX_RETRIES,
    MBLL_DEFAULT_AGE,
    MBLL_WAVELENGTH_WL1_NM,
    MBLL_WAVELENGTH_WL2_NM,
    SERIAL_PORT,
    SOURCE_DETECTOR_DISTANCE_CM,
    TIMEOUT,
    WAVELENGTH_660_CODE,
    WAVELENGTH_940_CODE,
)
from protocol import FrameReader, build_command_frame, parse_data_frame, send_frame_with_ack

# 用前若干秒的平均光强作为 OD 基线
BASELINE_SECONDS = 5.0
# MBLL 更新节流：至少间隔多少秒再算下一对（避免 GUI 卡顿）
UPDATE_INTERVAL_S = 0.1
# 绘图时间窗（秒）
WINDOW_SECONDS = 60.0
BP_LOW_HZ = 0.05
BP_HIGH_HZ = 0.5
BP_ORDER = 4
BP_TARGET_FS = 20.0


def butter_bandpass_sos(lowcut: float, highcut: float, fs: float, order: int = 4):
    """构造带通滤波器的 SOS 形式。"""
    nyq = 0.5 * fs
    if nyq <= 0 or lowcut >= highcut or highcut >= nyq:
        return None
    return butter(order, [lowcut / nyq, highcut / nyq], btype="band", output="sos")


def smart_bandpass(
    data: np.ndarray,
    fs: float,
    lowcut: float = BP_LOW_HZ,
    highcut: float = BP_HIGH_HZ,
    order: int = BP_ORDER,
    target_fs: float = BP_TARGET_FS,
) -> np.ndarray:
    """
    对 OD 数据做稳健带通。

    当采样率过高时，先降采样再滤波，最后升采样回来，
    可以减少数值不稳定和不必要的计算量。
    """
    if data.shape[1] < max(16, 3 * (order + 1) + 1):
        return data

    if fs > target_fs + 1:
        decim = int(round(fs / target_fs))
        fs_ds = fs / decim
        data_ds = resample_poly(data, up=1, down=decim, axis=1)
    else:
        decim, fs_ds, data_ds = 1, fs, data

    sos = butter_bandpass_sos(lowcut, highcut, fs_ds, order)
    if sos is None or data_ds.shape[1] < max(16, 3 * (order + 1) + 1):
        return data

    padlen = min(data_ds.shape[1] - 1, 3 * (order + 1))
    if padlen <= 0:
        return data

    data_bp = sosfiltfilt(sos, data_ds, axis=1, padtype="odd", padlen=padlen)
    if decim > 1:
        data_bp = resample_poly(data_bp, up=decim, down=1, axis=1)
    return data_bp


def open_serial() -> serial.Serial:
    return serial.Serial(SERIAL_PORT, baudrate=BAUD_RATE, timeout=TIMEOUT)


def _channel_info():
    """单通道双波长的通道名、波长、DPF、源探距离，与 data_analysis._channel_info 一致。"""
    ch_names = [CHANNEL_NAME, CHANNEL_NAME]
    ch_wls = [MBLL_WAVELENGTH_WL1_NM, MBLL_WAVELENGTH_WL2_NM]
    ch_dpfs = [
        get_dpf(MBLL_WAVELENGTH_WL1_NM, MBLL_DEFAULT_AGE),
        get_dpf(MBLL_WAVELENGTH_WL2_NM, MBLL_DEFAULT_AGE),
    ]
    ch_distances = [SOURCE_DETECTOR_DISTANCE_CM, SOURCE_DETECTOR_DISTANCE_CM]
    return ch_names, ch_wls, ch_dpfs, ch_distances


class SerialReaderThread(QtCore.QThread):
    """后台串口读线程，与 adc_live 相同逻辑：发启动命令、持续读 0x02、回 ACK、发信号。"""
    newData = QtCore.pyqtSignal(float, int, int)

    def __init__(self, ser: serial.Serial, parent=None):
        super().__init__(parent)
        self.ser = ser
        self.reader = FrameReader(ser)
        self.running = True
        self.start_time = time.time()

    def _emit(self, sample):
        t = time.time() - self.start_time
        self.newData.emit(t, sample.wavelength_code, sample.value)

    def _start_stream(self) -> bool:
        cmd = build_command_frame(True, DEFAULT_INTENSITY_MA)
        deadline = time.time() + max(ACK_TIMEOUT_SECONDS * 10, 0.2)
        for attempt in range(MAX_RETRIES + 1):
            self.ser.write(cmd)
            while time.time() < deadline:
                frame = self.reader.read_frame(timeout_seconds=min(TIMEOUT, max(0.01, deadline - time.time())))
                if frame is None:
                    continue
                if frame.frame_type == 0x02:
                    self._emit(parse_data_frame(frame))
                    return True
            deadline = time.time() + max(ACK_TIMEOUT_SECONDS * 10, 0.2)
        return False

    def run(self):
        started = self._start_stream()
        if not started:
            print("[hbo_hbr_live] Start command sent (max attempts reached). Keep waiting for data frames...")
        while self.running:
            frame = self.reader.read_frame(timeout_seconds=TIMEOUT)
            if frame is None or frame.frame_type != 0x02:
                continue
            self._emit(parse_data_frame(frame))
        try:
            send_frame_with_ack(self.ser, self.reader, build_command_frame(False, DEFAULT_INTENSITY_MA))
        except Exception:
            pass

    def stop(self):
        self.running = False


class MainWindow(QtWidgets.QWidget):
    """实时 HbO / HbR 坐标图。前几秒仅收数据建基线，之后每收到新双波长对就更新一条 MBLL 点。"""
    def __init__(self):
        super().__init__()
        pg.setConfigOption("background", "w")
        pg.setConfigOption("foreground", "k")
        self.setWindowTitle("S1_D1 HbO / HbR 实时")

        self.start_time = time.time()
        # 协议码 0x02=660 nm；0x01 在 MBLL 中按 data_analysis 使用 860 nm
        self.ref_660: float | None = None
        self.ref_wl1: float | None = None
        self.baseline_660: list[float] = []
        self.baseline_wl1: list[float] = []
        self.last_mbll_time = 0.0
        self.current_phase_wl: int | None = None
        self.current_phase_vals: list[float] = []
        self.current_phase_times: list[float] = []
        self.latest_rms_660: float | None = None
        self.latest_rms_wl1: float | None = None
        self.latest_rms_time_660: float | None = None
        self.latest_rms_time_wl1: float | None = None
        self.last_pair_time = -1.0

        self.time_660 = deque(maxlen=5000)
        self.data_660 = deque(maxlen=5000)
        self.time_wl1 = deque(maxlen=5000)
        self.data_wl1 = deque(maxlen=5000)

        self.time_hbo = deque(maxlen=3000)
        self.hbo_vals = deque(maxlen=3000)
        self.hbr_vals = deque(maxlen=3000)
        self.time_od = deque(maxlen=3000)
        # 行顺序与 data_analysis samples vstack 一致：wl1(0x01) 在上，660(0x02) 在下
        self.od_wl1_vals = deque(maxlen=3000)
        self.od_660_vals = deque(maxlen=3000)

        layout = QtWidgets.QVBoxLayout(self)
        self.plot = pg.PlotWidget(title="HbO / HbR 实时")
        self.plot.showGrid(x=True, y=True)
        self.plot.setLabel("bottom", "Time (s)")
        self.plot.setLabel("left", "Concentration (Δ)")
        self.plot.addLegend()
        self.plot.setXRange(0, WINDOW_SECONDS, padding=0)
        self.curve_hbo = self.plot.plot(pen=pg.mkPen("r", width=2), name="HbO")
        self.curve_hbr = self.plot.plot(pen=pg.mkPen("b", width=2), name="HbR")
        layout.addWidget(self.plot)

        self.status = QtWidgets.QLabel("建立基线…")
        layout.addWidget(self.status)

        self.timer = QtCore.QTimer()
        self.timer.timeout.connect(self._update_plot)
        self.timer.start(50)

    @QtCore.pyqtSlot(float, int, int)
    def on_new_data(self, elapsed: float, wavelength_code: int, value: int):
        if value <= 0:
            return
        if wavelength_code not in (WAVELENGTH_660_CODE, WAVELENGTH_940_CODE):
            return

        # 与离线 sliding_window_rms 一致：按波长连续段切段，段结束时用 RMS 代表该段。
        if self.current_phase_wl is None:
            self.current_phase_wl = wavelength_code
        elif wavelength_code != self.current_phase_wl:
            self._finalize_phase()
            self.current_phase_wl = wavelength_code
            self.current_phase_vals.clear()
            self.current_phase_times.clear()

        self.current_phase_vals.append(float(value))
        self.current_phase_times.append(elapsed)

    def _finalize_phase(self):
        if self.current_phase_wl is None or not self.current_phase_vals:
            return

        phase_rms = float(np.sqrt(np.mean(np.square(np.asarray(self.current_phase_vals, dtype=float)))))
        phase_time = float(np.mean(self.current_phase_times))

        if self.current_phase_wl == WAVELENGTH_660_CODE:
            self.latest_rms_660 = phase_rms
            self.latest_rms_time_660 = phase_time
            self.time_660.append(phase_time)
            self.data_660.append(phase_rms)
            if self.ref_660 is None and phase_time <= BASELINE_SECONDS:
                self.baseline_660.append(phase_rms)
        elif self.current_phase_wl == WAVELENGTH_940_CODE:
            self.latest_rms_wl1 = phase_rms
            self.latest_rms_time_wl1 = phase_time
            self.time_wl1.append(phase_time)
            self.data_wl1.append(phase_rms)
            if self.ref_wl1 is None and phase_time <= BASELINE_SECONDS:
                self.baseline_wl1.append(phase_rms)

        # 用串口时间戳判断：满 BASELINE_SECONDS 且有两路数据则固定基线
        if (
            self.ref_660 is None
            and self.ref_wl1 is None
            and phase_time >= BASELINE_SECONDS
            and self.baseline_660
            and self.baseline_wl1
        ):
            self.ref_660 = float(np.mean(self.baseline_660))
            self.ref_wl1 = float(np.mean(self.baseline_wl1))
            self.status.setText(
                f"基线就绪 ref_660={self.ref_660:.0f} "
                f"ref_wl1({int(MBLL_WAVELENGTH_WL1_NM)}nm)={self.ref_wl1:.0f}"
            )

        if (
            self.ref_660 is not None
            and self.ref_wl1 is not None
            and self.latest_rms_660 is not None
            and self.latest_rms_wl1 is not None
            and self.latest_rms_time_660 is not None
            and self.latest_rms_time_wl1 is not None
        ):
            t = (self.latest_rms_time_660 + self.latest_rms_time_wl1) * 0.5
            if t <= self.last_pair_time:
                return
            if (t - self.last_mbll_time) < UPDATE_INTERVAL_S:
                return

            i_660 = max(self.latest_rms_660, 1.0)
            i_wl1 = max(self.latest_rms_wl1, 1.0)
            delta_od_660 = -np.log10(i_660 / self.ref_660)
            delta_od_wl1 = -np.log10(i_wl1 / self.ref_wl1)
            self.time_od.append(t)
            self.od_wl1_vals.append(delta_od_wl1)
            self.od_660_vals.append(delta_od_660)

            delta_od_hist = np.vstack(
                [
                    np.asarray(self.od_wl1_vals, dtype=float),
                    np.asarray(self.od_660_vals, dtype=float),
                ]
            )
            od_times = np.asarray(self.time_od, dtype=float)
            dt = np.median(np.diff(od_times)) if od_times.size >= 2 else np.nan
            fs = 1.0 / dt if np.isfinite(dt) and dt > 0 else 1.0
            delta_od_filt = smart_bandpass(
                delta_od_hist,
                fs,
                lowcut=BP_LOW_HZ,
                highcut=BP_HIGH_HZ,
                order=BP_ORDER,
            )
            delta_od = delta_od_filt[:, -1:].astype(float, copy=False)
            ch_names, ch_wls, ch_dpfs, ch_distances = _channel_info()
            try:
                delta_c, names, types = mbll_hbo_hbr(
                    delta_od,
                    ch_names,
                    ch_wls,
                    ch_dpfs,
                    ch_distances,
                    unit="cm",
                    table="wray",
                )
            except Exception:
                return
            flat = np.ravel(delta_c)
            if flat.size < 2:
                return
            hbo_val = float(flat[0])
            hbr_val = float(flat[1])
            self.last_mbll_time = t
            self.last_pair_time = t
            self.time_hbo.append(t)
            self.hbo_vals.append(hbo_val)
            self.hbr_vals.append(hbr_val)
            self.status.setText(f"HbO={hbo_val:.4e}  HbR={hbr_val:.4e}  t={t:.2f}s")

    def _update_plot(self):
        if self.time_hbo:
            self.curve_hbo.setData(list(self.time_hbo), list(self.hbo_vals))
            self.curve_hbr.setData(list(self.time_hbo), list(self.hbr_vals))
            t_max = max(self.time_hbo)
            x_min = max(0.0, t_max - WINDOW_SECONDS)
            self.plot.setXRange(x_min, max(t_max, WINDOW_SECONDS), padding=0)


def main():
    print(f"[hbo_hbr_live] Opening {SERIAL_PORT} @ {BAUD_RATE} ...")
    ser = open_serial()
    ser.reset_input_buffer()
    app = QtWidgets.QApplication(sys.argv)
    window = MainWindow()
    window.show()
    thread = SerialReaderThread(ser)
    thread.newData.connect(window.on_new_data)
    thread.start()
    app.aboutToQuit.connect(lambda: (thread.stop(), thread.wait(2000), ser.close()))
    sys.exit(app.exec_())


if __name__ == "__main__":
    main()

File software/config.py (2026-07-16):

"""
双接收源五波长 fNIRS 上位机的集中配置文件。

这里统一放置：
1. 串口参数
2. 26B 协议常量
3. S1-D1 / S1-D2 几何与五波长表
4. HbO / HbR / Cyt 反演、输出通道选择与输出文件名
"""

from __future__ import annotations

from dataclasses import dataclass
from typing import Literal

# 串口端口号。Windows 例如 "COM5"，Linux/macOS 可写成 /dev/ttyUSB0 之类。
SERIAL_PORT = "COM6"

# 串口基础参数
BAUD_RATE = 115200
TIMEOUT = 0.05
# 设备标称采样率（Hz），用于重建等间隔时间戳。
SAMPLING_RATE_HZ = 250.0

# 安卓 Host TCP Protocol 参数。解码端作为 TCP Server，安卓主动连接。
HOST_TCP_LISTEN_HOST = "0.0.0.0"
HOST_TCP_DEFAULT_PORT = 9000
HOST_TCP_PROTOCOL_VERSION = 1
HOST_TCP_MAX_BODY_BYTES = 4 * 1024 * 1024

# 26B 协议固定帧格式
FRAME_HEADER = bytes((0x55, 0xAA))
FRAME_LENGTH = 0x1A
FRAME_PAYLOAD_SIZE = 21

# 帧类型定义
FRAME_TYPE_COMMAND = 0x01
FRAME_TYPE_DATA = 0x02
FRAME_TYPE_ACK = 0x03

# ACK 等待与重发策略。
ACK_TIMEOUT_SECONDS = 0.05
MAX_RETRIES = 2

# 默认下发的命令参数
DEFAULT_INTENSITY_MA = 0x18
DEFAULT_STREAM_ENABLED = True
DEFAULT_COMMAND_CHANNEL_CODE = 0x01

# 默认通道名保留给旧脚本兜底；主处理链路使用 DETECTOR_CHANNELS。
CHANNEL_NAME = "S1_D1"
SOURCE_DETECTOR_DISTANCE_CM = 3.0

# 数据帧 payload byte0：两路均未点亮
WAVELENGTH_OFF_CODE = 0x00
DETECTOR_OFF_CODE = 0x00

# 数据帧 payload byte6（4 字节采样值之后的第一字节）：采集通道位。
# 0x01=通道1，0x02=通道2。0x00（未带通道位/旧固件）归入 DEFAULT_CHANNEL_CODE。
CHANNEL_OFF_CODE = 0x00
DEFAULT_CHANNEL_CODE = 0x01

# ---------------------------------------------------------------------------
# 输出通道选择（离线 processed_output、在线回传安卓、live 曲线均使用此通道）
# 可选: "S1_D1" | "S1_D2" | "S1_D1_ssr"
# ---------------------------------------------------------------------------
OutputChannelName = Literal["S1_D1", "S1_D2", "S1_D1_ssr"]
OUTPUT_CHANNEL: OutputChannelName = "S1_D1_ssr"
VALID_OUTPUT_CHANNELS: tuple[OutputChannelName, ...] = ("S1_D1", "S1_D2", "S1_D1_ssr")

# ---------------------------------------------------------------------------
# 在线回传安卓的模式与显示单位
# ---------------------------------------------------------------------------
# "full_replace"       : 旧逻辑，每 tick 对全会话非因果重算并整段重发（历史会变）。
# "causal_incremental" : 路线 B，因果 IIR 滤波 + 仅追加新样本（历史不再变，量纲固定）。
OnlineModeName = Literal["full_replace", "causal_incremental"]
ONLINE_MODE: OnlineModeName = "causal_incremental"

# 回传安卓前对浓度做显示换算：摩尔(M) × LIVE_CONC_SCALE，并附带单位标签。
# 1.0 → 保持原始摩尔(M)，与离线 processed_output.csv 同量纲；1e6 → 微摩尔(μM)。
LIVE_CONC_SCALE = 1.0
LIVE_CONC_UNIT = "M"
# 是否减去基线窗均值做锚定（让每条曲线从 0 起算，run 之间幅度可比）。
LIVE_BASELINE_ANCHOR = False
# 是否向安卓 live_analysis_batch 附带 delta_thb（HbO+HbR）。安卓未升级解析前可设 False。
LIVE_SEND_DELTA_THB = True
# 是否向安卓 live_analysis_batch 附带 thi / delta_thi（固定基线伪绝对总血红蛋白）。
# thi = HbO_abs + HbR_abs（与 rSO₂ 同一套基线假设，绝对量 ≈ 基线 HbT）；
# delta_thi = thi − 基线 HbT（相对基线的变化，≈0 起算）。安卓未升级解析前可设 False。
LIVE_SEND_THI = True

# ---------------------------------------------------------------------------
# 贴肤/未贴实时判定（搭在 live_analysis_batch 上，按采集通道 ch1/ch2 各判一次）
# ---------------------------------------------------------------------------
# 两级判据（近窗 SKIN_CONTACT_WINDOW_S 秒，只看原始光强，不做 MBLL/SSR），经时间防抖：
#   ① 压住？   短距 S1_D2 近窗中位数 ≥ SKIN_CONTACT_PRESS_MIN → 有贴住（否则悬空/未贴）
#   ② 是组织？ 短距 810nm/700nm 中位数比 ≥ SKIN_CONTACT_TISSUE_RATIO_MIN → 手臂/皮肤
#              低于阈值 → 桌子/硬物，**不算贴肤**（skin_contact=False）
# 700nm 是脱氧血红蛋白强吸收带：组织里的血把 700 压低 → 810/700 升高；桌子无血 → 比值低。
# 说明：长距 S1_D1 当前采集处于饱和（~6.6M 近常数、对空气也满值），信息为零，故判据只用短距。
# 阈值取自实采标定（2026-07-16 系列，ch2，降增益后 S1_D2 五波长脱饱和）；换增益/肤色需复标。
SKIN_CONTACT_WINDOW_S = 5.0
SKIN_CONTACT_MIN_SAMPLES = 5
SKIN_CONTACT_DEBOUNCE_S = 3.0
# ① 压住下限（短距原始 ADC）：手臂/桌子压住时 S1_D2 中位 ~3–5M，悬空 ~0.3–1M。
SKIN_CONTACT_PRESS_DETECTOR = "S1_D2"
SKIN_CONTACT_PRESS_MIN = 2_000_000
# ② 组织比值门（短距 810nm / 700nm 中位数）：手臂 ~0.79、桌子 ~0.66，阈值取中点。
SKIN_CONTACT_TISSUE_RATIO_HIGH_NM = 810.0
SKIN_CONTACT_TISSUE_RATIO_LOW_NM = 700.0
SKIN_CONTACT_TISSUE_RATIO_MIN = 0.72
# 是否向安卓 live_analysis_batch 附带 skin_contact 字段。安卓未升级解析前可设 False。
LIVE_SEND_SKIN_CONTACT = True


def _nm_suffix(nm: float) -> str:
    if nm == int(nm):
        return str(int(nm))
    return str(nm).replace(".", "_")


@dataclass(frozen=True)
class WavelengthChannel:
    """
    单路活跃波长。

    - code: 协议 Wavelength 列取值（LED1..LED5）
    - emitter_nm: 光源标称波长，用于 CSV 列名后缀（如 S1_D1_850）
    - mbll_nm: MBLL / DPF 反演用的光学波长
    """

    code: int
    emitter_nm: float
    mbll_nm: float

    @property
    def intensity_column(self) -> str:
        return intensity_column_name(self.emitter_nm)


@dataclass(frozen=True)
class DetectorChannel:
    """
    单个接收源形成的物理通道。

    - code: 协议 DetectorId / SensorId 取值（PD1=0x01，PD2=0x02）
    - name: 输出列名前缀（S1_D1 / S1_D2）
    - distance_cm: 源探距离，进入 MBLL pathlength
    """

    code: int
    name: str
    distance_cm: float


@dataclass(frozen=True)
class AcquisitionChannel:
    """
    单个采集通道（硬件通道，数据帧 payload byte6 = ChannelId）。

    与「接收源」(DetectorChannel) 正交：每个采集通道内部仍各自包含完整的
    双接收源（S1_D1/S1_D2）× 五波长，整条反演链路在每个通道内各跑一套。

    - code: 协议 ChannelId 取值（通道1=0x01，通道2=0x02）
    - name: 输出文件名后缀 / 日志标识（ch1 / ch2）
    """

    code: int
    name: str
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

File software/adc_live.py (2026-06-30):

"""
双接收源实时 ADC 曲线查看器（默认显示 S1_D1@850nm 与 S1_D2@850nm）。
"""

from __future__ import annotations

import sys
import time
from collections import deque

import numpy as np
import pyqtgraph as pg
import serial
from PyQt5 import QtCore, QtWidgets
from scipy.signal import butter, lfilter, sosfilt

from config import (
    ACK_TIMEOUT_SECONDS,
    BAUD_RATE,
    DEFAULT_INTENSITY_MA,
    DETECTOR_CHANNELS,
    MAX_RETRIES,
    SERIAL_PORT,
    TIMEOUT,
    WAVELENGTH_850_CODE,
    WAVELENGTH_OFF_CODE,
)
from protocol import FrameReader, build_command_frame, parse_data_frame, send_frame_with_ack


def open_serial() -> serial.Serial:
    """按 config.py 中的参数打开串口。"""
    return serial.Serial(SERIAL_PORT, baudrate=BAUD_RATE, timeout=TIMEOUT)


def frame_to_hex(frame_bytes: bytes) -> str:
    """把二进制帧转成十六进制字符串，便于调试打印。"""
    return " ".join(f"{b:02X}" for b in frame_bytes)


class SerialReaderThread(QtCore.QThread):
    """后台串口读取线程，避免 GUI 主线程被串口阻塞。"""
    newData = QtCore.pyqtSignal(float, int, int, int)

    def __init__(self, ser: serial.Serial, parent=None):
        super().__init__(parent)
        self.ser = ser
        self.reader = FrameReader(ser)
        self.running = True
        self.start_time = time.time()

    def _emit_sample(self, sample):
        """把协议层的 DataSample 转成 GUI 能直接消费的信号。"""
        elapsed = time.time() - self.start_time
        print(
            "[adc_live] Data frame received:",
            f"detector={sample.detector_code}",
            f"wavelength_code=0x{sample.wavelength_code:02X}",
            f"value={sample.value}",
        )
        self.newData.emit(elapsed, sample.detector_code, sample.wavelength_code, sample.value)

    def _start_stream(self) -> bool:
        """
        启动采集。

        当前固件版本不返回 ACK。
        这里只检查是否开始收到 0x02 数据帧，收到即视为启动成功。
        """
        command = build_command_frame(True, DEFAULT_INTENSITY_MA)
        startup_timeout = max(ACK_TIMEOUT_SECONDS * 10, 0.2)

        for attempt in range(MAX_RETRIES + 1):
            print(f"[adc_live] Sending start command frame (attempt {attempt + 1})...")
            print(f"[adc_live] TX start raw={frame_to_hex(command)}")
            self.ser.write(command)

            deadline = time.time() + startup_timeout
            while time.time() < deadline:
                frame = self.reader.read_frame(timeout_seconds=min(TIMEOUT, max(0.01, deadline - time.time())))
                if frame is None:
                    continue
                if frame.frame_type == 0x02:
                    sample = parse_data_frame(frame)
                    print("[adc_live] Stream became active.")
                    self._emit_sample(sample)
                    return True
                print(f"[adc_live] Ignored startup non-data frame type: 0x{frame.frame_type:02X}")

        print("[adc_live] No data frame received after start command. Reader thread exits.")
        return False

    def run(self):
        """线程主循环：先启动流，再持续读取数据帧。"""
        started = self._start_stream()
        if not started:
            print("[adc_live] Start command sent (max attempts reached). Keep waiting for data frames...")

        while self.running:
            frame = self.reader.read_frame(timeout_seconds=TIMEOUT)
            if frame is None:
                continue
            if frame.frame_type != 0x02:
                print(f"[adc_live] Ignored frame type: 0x{frame.frame_type:02X}")
                continue

            sample = parse_data_frame(frame)
            self._emit_sample(sample)

        try:
            print("[adc_live] Sending stop command frame...")
            stop_command = build_command_frame(False, 0x00)
            print(f"[adc_live] TX stop raw={frame_to_hex(stop_command)}")
            send_frame_with_ack(
                self.ser,
                self.reader,
                stop_command,
            )
        except Exception:
            pass

    def stop(self):
        self.running = False


class MainWindow(QtWidgets.QWidget):
    """双接收 @850nm 实时曲线（S1_D1 / S1_D2）。"""
    def __init__(self):
        super().__init__()
        pg.setConfigOption("background", "w")
        pg.setConfigOption("foreground", "k")
        self.setWindowTitle("双接收 ADC 实时监视 (850nm)")

        self.window_seconds = 10.0
        self.max_points = 3000
        d1_name = DETECTOR_CHANNELS[0].name
        d2_name = DETECTOR_CHANNELS[1].name
        self.data_d1 = deque(maxlen=self.max_points)
        self.data_d2 = deque(maxlen=self.max_points)
        self.time_d1 = deque(maxlen=self.max_points)
        self.time_d2 = deque(maxlen=self.max_points)

        main_layout = QtWidgets.QVBoxLayout(self)
        top_layout = QtWidgets.QHBoxLayout()
        top_layout.addStretch()
        for color, label in (("red", f"{d1_name}@850"), ("green", f"{d2_name}@850")):
            item = QtWidgets.QWidget()
            item_layout = QtWidgets.QHBoxLayout(item)
            item_layout.setContentsMargins(0, 0, 0, 0)
            square = QtWidgets.QLabel()
            square.setFixedSize(15, 15)
            square.setStyleSheet(f"background-color: {color}; border: 1px solid black;")
            text_label = QtWidgets.QLabel(label)
            item_layout.addWidget(square)
            item_layout.addWidget(text_label)
            top_layout.addWidget(item)
        top_layout.addStretch()
        main_layout.addLayout(top_layout)

        # 滤波器控制区：None / Lowpass / Bandpass / Threshold
        filter_layout = QtWidgets.QGridLayout()
        filter_layout.setHorizontalSpacing(8)
        filter_layout.setVerticalSpacing(6)

        self.filter_mode_combo = QtWidgets.QComboBox()
        self.filter_mode_combo.addItems(["None", "Lowpass", "Bandpass", "Threshold"])
        filter_layout.addWidget(QtWidgets.QLabel("滤波模式"), 0, 0)
        filter_layout.addWidget(self.filter_mode_combo, 0, 1)

        self.lowpass_cutoff_spin = QtWidgets.QDoubleSpinBox()
        self.lowpass_cutoff_spin.setRange(0.01, 1000.0)
        self.lowpass_cutoff_spin.setDecimals(3)
        self.lowpass_cutoff_spin.setValue(1.0)
        self.lowpass_cutoff_spin.setSuffix(" Hz")
        filter_layout.addWidget(QtWidgets.QLabel("低通截止"), 0, 2)
        filter_layout.addWidget(self.lowpass_cutoff_spin, 0, 3)

        self.band_low_spin = QtWidgets.QDoubleSpinBox()
        self.band_low_spin.setRange(0.001, 1000.0)
        self.band_low_spin.setDecimals(3)
        self.band_low_spin.setValue(0.05)
        self.band_low_spin.setSuffix(" Hz")
        filter_layout.addWidget(QtWidgets.QLabel("带通下限"), 0, 4)
        filter_layout.addWidget(self.band_low_spin, 0, 5)

        self.band_high_spin = QtWidgets.QDoubleSpinBox()
        self.band_high_spin.setRange(0.001, 1000.0)
        self.band_high_spin.setDecimals(3)
        self.band_high_spin.setValue(0.1)
        self.band_high_spin.setSuffix(" Hz")
        filter_layout.addWidget(QtWidgets.QLabel("带通上限"), 0, 6)
        filter_layout.addWidget(self.band_high_spin, 0, 7)
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

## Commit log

2026-02-03 增加文件
2026-02-03 bug修改
2026-02-09 增加nirs数据阅读器
2026-02-24 注释汉化
2026-02-25 算法文档编写
2026-03-10 更新近红外的数据处理流程文档
2026-03-16 qoder的repowiki更新
2026-03-16 根目录 README.md：改为「fNIRS 上位机软件」说明，去掉下位机/硬件验证描述，只保留串口配置、安装依赖、采集与处理步骤及当前目录结构。
    [AnalogMux.SchDoc, Buffer.SchDoc, Connectors.SchDoc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]
2026-03-16 将整个 software/ 目录重构为基于 26 字节新串口协议的单通道 S1_D1 架构，固定源探距离为 3.0 cm，保留双波长 660/940nm 处理流程。 新增并统一使用 protocol.py 封装帧打包/解析、ACK 重试与流式读取逻辑，所有上位机程序通过该模块访问串口数据。 重写 fNIRS_processing.py 采集与预处理/MBLL/CBSI 流程，产出 process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
    [adc_live.py, config.py, fNIRS_processing.py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]
2026-03-17 跑通数据处理流程，可以生成hbo、hbr曲线
2026-03-17 优化模拟下位机脚本
2026-03-17 取消对数据帧的应答机制
2026-03-17 怎加实施采样率显示
2026-03-19 更新repowiki
2026-03-30 修改波长对应关系，01：940nm，02：660nm
2026-03-31 修改了下通讯协议中光强位，并先注释应答帧判断
2026-03-31 修改数据接受逻辑，发送三次采集后开等待数据
2026-03-31 修改协议数据位为4字节，大端序
2026-03-31 修改了下阈值抑制范围
2026-04-14 更新：1、增加adc傅里叶变换展示、2、优化全流程分析过程
2026-04-14 给adc展示脚本增加滤波器选择
2026-04-14 增加计算rso2的基线假设法
2026-04-15 加了一些注释
2026-04-17 1、增加一些注释，2、给hno和hbr实时波形显示脚本增加带通滤波器
2026-04-23 增加新的数据处理脚本
2026-05-18 第一次对齐
2026-05-18 带通滤波对齐
2026-05-18 refactor(software): 用 WAVELENGTH_CHANNELS 统一波长与配对逻辑
    将协议码、光源标称波长与 MBLL 反演波长集中到 config，自动生成光强列名；fNIRS_processing 以周期聚合替代硬编码的 940/660 相邻配对，便于后续增改波长。
2026-06-01 完成和安卓上位机的通讯协议的初稿
2026-06-02 增加TCP通讯模块并和安卓上位机初步调通
2026-06-08 新增在线模式
2026-06-10 增加注释
2026-06-12 重构算法架构
2026-06-15 增加解码器端的发送给安卓的数据的展示图机制
2026-06-15 对比离线在线版本
2026-06-15 修改更新逻辑每次发送全部数据（因为是非因果滤波）
2026-06-16 删除一些图
2026-06-16 更新图片
2026-06-30 改造成五波长三色团版本
2026-06-30 更新说明文件
2026-07-02 更新一版流式在线方式
2026-07-02 增加Δthb
2026-07-03 增加Δthi、thi
2026-07-03 和安卓端对齐基线设置功能
2026-07-08 皮肤检测改造文件
2026-07-08 重写用到的nirsimple包的函数mbll_core
2026-07-11 改成双通道，初步通过联调
2026-07-13 增加log功能
2026-07-15 贴肤检测功能联调通过
2026-07-16 贴肤检测增加一个判据，用于区分贴着桌面和贴着皮肤
2026-07-20 导入config问题修改
2026-08-31 验证SRS链路是否有问题
2026-09-01 验证 SSR 有效性：合成 HRF 真值 + 阴性对照 + MNE 交叉核对 新增 Monte Carlo 分层头模型，初步量化 SRS 的脑/颅外灵敏度
2026-09-01 精简 srs_mc_layered：移除 validate_layers 子命令
    保留 --validate 与 --run 两条入口，删去分层自检实现与对应 CLI 说明。
2026-09-04 验证在线因果滤波相对离线的一致性（找出问题所在），完善 SRS 路线与探头几何选型
2026-10-10 新增SRS验证模块
2026-10-12 Ran a command 三波长定版：停用 810nm，确定量程，标定文件归置
    810nm 第二次停用，这次是 4cm 通道的非光学伪影（与 10-10 那次无关）：
    完全遮光下 810@4cm 在档位 90/130/150 读 300 / 69,885 / 124,833，
    其余四路始终在零附近。不是干净的电流阈值 —— 档位 90 也出现过 43,080，
    限档挡不住，只能移出反演。950 经真不透遮挡验证为干净。
    代价为负：预期 TOI 重复性 ±3.66 → ±1.84 %O₂（810 本就是离散最大的一路）。
    hardware.py
    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
2026-10-22 SRS 把 flags 与 config_notes 拆开并加 tHb/光谱残差自检；新增 MBLL 解码器与周期时间戳
2026-10-23 SRS 增加派生相对量与基线；界面并排显示 TOI 与 ΔHbO/ΔHbR
    - srs.py 新增 Baseline / Derived / AucAccumulator，由绝对浓度减基线得
    ΔHbO/ΔHbR/ΔtHb/THI/ΔTHI/ΔTOI 与 AUC；纯算术，可移植安卓端。
    - online.py 加第四绘图行与「校准基线」按钮；selftest 新增 t17，158/158 通过。
    - 新增 .claude/变更记录/，记「为什么这么改」和「试过什么没成」，与 git diff 互补。
    - 遗留：online.py:807 不可达代码；带 flag 的点仍进 TOI 曲线与基线。
2026-10-26 online 改版：基线/AUC 状态机进逻辑层，出值 120~381s → 59s，MBLL 移出
    - srs.py 新增 BaselineManager / SettleGate，基线与 AUC 的判断全在这一层（安卓端同一份行为）；
    AUC 警戒线改为参考 TOI×0.8，旧口径在静止体模上 10 分钟凭空攒 662~1013 %·s；稳定判据只当
    指示灯不拦基线 —— 等待买到的精度 ≤0.5 点，在 ΔTOI 噪声底以下，却让 8 份归档里 3 份设不上基线。
    - online.py 主页五格 + 八个带标签读数格、时间窗、事件标记、数据时刻时间轴，μa 移到调试页；
    THI 按 MOC400 用比值口径（基线=1.00）并保留 µM 指数。
    - MBLL 从 online 移除（模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
2026-10-28 数据更新
2026-10-28 online增加通道切换功能
2026-10-29 多通道同时计算：每通道一条流水线，可单独开关与调光强
    - 新增 srs_cal/chpipe.py：ChannelPipeline（扣暗→滑窗→稳健聚合→反演→派生量）
    与 TimeBase（各通道共享时间原点）。online 的 25 个测量态属性**原样搬进去**，
    窗口改持 pipes{通道: 流水线}，并用 32 个转发 property 指向"当前查看的通道"
    —— 界面代码一行未改，等价性才验得了。
    验收：5 份真实归档 × 2 通道 = 10 个组合、156 个 TOI 点，toi/thi/t/td/ta/auc/
    d_hist/mua 全部逐点逐位相同；搬走的五个方法去注释后逐行比对也完全一致。
    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
